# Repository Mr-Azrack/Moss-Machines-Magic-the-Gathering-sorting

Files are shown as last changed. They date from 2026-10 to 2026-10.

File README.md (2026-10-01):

# Moss Machine - Open Source Magic: The Gathering - MTG - Sorting & Recognition

<p align="center">
  
</p>

Welcome to the Moss Machine project! This open-source initiative provides a comprehensive system for automating the sorting, recognition, and management of Trading Card Game (TCG) cards. The system supports **317 different card games** including Magic: The Gathering, Pokemon, Yu-Gi-Oh!, and many others.

---

### Overview

The Moss Machine combines perceptual hash-based computer vision, multi-threaded processing, and hardware integration to create a high-performance, scalable card sorting solution. Whether you're a collector, player, or developer, this project offers tools and guidance to build your own automated card sorting system with speeds capable of processing cards in under 2 seconds per scan.

---

## Features

- **Open Source & Community Driven**  
  Fully open source code with transparent development. Contributions and modifications are encouraged—please credit the original source when creating derivatives.

- **Multi-Game Support**  
  - Supports **317 different trading card games** from a unified SQLite database
  - Includes Magic: The Gathering, Pokemon, Yu-Gi-Oh!, Flesh and Blood, Lorcana, and 300+ more
  - Filterable by game, set, rarity, and foil type for precise scanning
  - Automatic database download from server if not found locally

- **High-Performance Recognition Engine**  
  - **Perceptual hashing (pHash)** with 256-bit hash using 16x16 hash size for robust image matching
  - **RGB channel separation** - computes separate hashes for Red, Green, and Blue channels for improved accuracy
  - **Multi-threaded scanning** - parallel processing across games with 8 worker threads by default
  - **Early termination** - stops scanning immediately when exact match (distance = 0) is found
  - **Hash caching** - optional in-memory cache for popular games (Magic, Pokemon, Yu-Gi-Oh) for faster repeat scans
  - **Adaptive threshold scanning** - progressive tightening from strict to relaxed thresholds
  - **Quick distance pre-filtering** - rejects bad matches early using single-channel checks
  - **Hamming distance** calculation for fast hash comparison
  - **Average scan time** -: ~2 seconds per card across 317 games

- **Advanced Image Processing**  
  - **OpenCV-based** card detection with contour finding and perspective correction
  - **Automatic card orientation** - handles cards at any angle with 4-point perspective transform
  - **Region-based hashing** - uses top-left 745x745px crop for consistent hash generation
  - **VL6180X ToF sensor integration** - hardware distance sensing for precise Z-axis control during pickup/release
  - **Real-time camera feed processing** with automatic card detection

- **Flexible Sorting Modes**  
  - **Color sorting** - White, Blue, Black, Red, Green, Multicolor, Colorless, Land (Basic/Nonbasic)
  - **Mana value (CMC)** - Bins from 1-8+ with overflow handling
  - **Set code** - Sort by expansion/set with token detection
  - **Price-based** - 14 price brackets from $0.02 to $128+ with configurable thresholds
  - **Card type** - Creature, Artifact, Enchantment, Instant, Sorcery, Planeswalker, Battle, Land, Token
  - **Alphabetical (A-Z)** - First letter sorting with 0-9 bin for numbers/symbols
  - **Rarity** - Common, Uncommon, Rare, Mythic, Special, Bonus, Promo
  - **Finish** - Foil, Nonfoil, Both (for cards with multiple finishes)
  - **Buy mode** - Custom price threshold for purchase evaluation

- **Hardware Integration**  
  - **Arduino Mega control** via serial communication (PySerial)
  - **3-axis stepper motor control** (X, Y, Z axes plus dual E-motors for coordinated movement)
  - **Endstop sensors** on all 6 positions (X/Y/Z min/max) for safety and homing
  - **Dual vacuum system** - separate pickup and release control
  - **LED lighting control** for optimal camera visibility
  - **16x2 LCD display** (I2C) for real-time machine status
  - **34-tray sorting system** with configurable tray assignments
  - **Automatic homing and calibration** with configurable course correction
  - **Overflow tray (34)** and reject bin (33) with automatic routing
  - **Configurable parameters**: pickup/drop distances, movement speeds, thresholds, calibration multipliers
  - **Safety features**: endstop monitoring, retry logic (10 attempts), timeout handling
  - **Start/Stop machine states** - prevents accidental movements during parameter changes

- **GUI Control Interface**  
  - **Enhanced Tkinter GUI** with tabbed interface (Scanner, Arduino, Export)
  - **Live camera feed** display with real-time card detection overlay
  - **Manual and auto-scan modes** with configurable cooldown
  - **Arduino monitoring** - real-time sensor data display (range, endstops, motor states)
  - **Motor control panel** - manual control of X, Y, Z, E0, E1 motors
  - **Parameter upload/fetch** - live parameter editing and synchronization
  - **CSV export** - scan history with auto-export option
  - **Inventory tracking** - reject duplicate cards automatically
  - **Game/Set/Rarity/Foil filters** with dropdown selection
  - **Status logging** with color-coded messages

- **Performance & Reliability**  
  - **Detailed statistics** - tracks scans, total time, average time, cards checked, cache hits
  - **Retry mechanisms** - up to 10 pickup attempts with distance sensor verification
  - **Periodic homing** - automatic recalibration every N cards (configurable)
  - **Course correction** - fine-tune X/Y positioning to prevent drift
  - **Thread-local database connections** for safe multi-threading
  - **Confidence scoring** - percentage-based match quality with configurable minimum thresholds
  - **Duplicate detection** via inventory file tracking

- **Command Line Interface**  
  - Interactive mode with sorting menu
  - Realtime webcam mode for continuous scanning
  - Single-image scanning with detailed match output
  - Game/set/rarity/foil filtering via command-line arguments
  - List all games, sets, rarities, and foil types
  - Adjustable threshold and top-N results
  - Cache preloading option
  - Serial port and baud rate configuration

- **Configurable & Extensible**  
  - All movement parameters configurable (speeds, distances, calibration multipliers)
  - Adjustable hash matching thresholds (default: 10, lower = stricter)
  - Customizable tray assignments with automatic overflow
  - Price threshold configuration for buy mode
  - Worker thread count adjustable (default: 8)
  - Scan cooldown adjustable (default: 2.0 seconds)
  - Game-specific foil type and rarity detection

- **Technology Stack**  
  - **Python 3**: OpenCV (cv2), ImageHash, Pillow (PIL), PySerial, NumPy, SQLite3, Threading, Tkinter
  - **Database**: Unified SQLite database with 317 game-specific card tables, games table, sets table, and others (future development)
  - **Arduino**: C++ firmware for Mega 2560, Stepper motor control, I2C LCD, VL6180X ToF sensor (Adafruit library)
  - **Hardware**: RAMPS 1.4 board, A4988 stepper drivers, NEMA 17 motors, endstop switches, vacuum pumps, LED strips  

---

## System Architecture

### Software Components

1. **optimized_scanner.py** - Core recognition engine
   - `OptimizedCardScanner` class with multi-threaded game scanning
   - Perceptual hash computation and comparison
   - Database connection pooling (thread-local connections)
   - Adaptive threshold scanning
   - Serial communication with Arduino
   - Real-time webcam mode
   - Command-line interface with extensive filtering options

2. **gui_interface_enhanced.py** - GUI control interface
   - Tabbed interface (Scanner, Arduino, Export)
   - Live camera feed with card detection visualization
   - Arduino parameter management and monitoring
   - CSV export with scan history
   - Game/Set/Rarity/Foil filtering
   - Auto-scan and manual scan modes

3. **Main.ino** - Arduino firmware
   - 3-axis stepper motor control (X, Y, Z + E0, E1 dual drive)
   - VL6180X ToF sensor integration for distance measurement
   - Endstop monitoring (6 endstops: X/Y/Z min/max)
   - Dual vacuum system control
   - LCD status display (16x2 I2C)
   - Serial command parser with start/end markers
   - 34-tray coordinate system with automatic routing
   - Homing and calibration routines
   - State machine (Stopped/Started) for safe operation

### Database Structure

- **unified_card_database.db** (SQLite)
  - `games` table: 317 games with ID, name, display_name, total_cards
  - `cards_*` tables: One table per game (e.g., cards_magic, cards_pokemon, cards_yugioh)
  - `sets` table: Set information per game with set codes and card counts
  - Card columns: unique_id, product_id, set_code, rarity, name, series, number, prices (low/mid/high/market/imputed), subTypeName (foil type), has_image, phash (r_phash, g_phash, b_phash), extCardType
  - Optional: SKU columns (111 columns for condition/language/printing combinations)

### Hardware Components

- **Arduino Mega 2560** - Main controller
- **RAMPS 1.4** - Motor driver board
- **A4988 Stepper Drivers** (5x) - Motor control
- **NEMA 17 Stepper Motors** (5x) - X, Y, Z, E0, E1 axes
- **VL6180X ToF Sensor** - Distance measurement (I2C)
- **Endstop Switches** (6x) - Limit switches for safety
- **16x2 LCD Display** (I2C) - Status display
- **Vacuum Pumps** (2x) - Card pickup and release
- **LED Strip** - Lighting for camera
- **Webcam** - Card image capture

---

## Quick Start

### Software Setup

1. **Install Python dependencies:**
   ```bash
   pip install opencv-python pillow imagehash pyserial numpy
   ```

2. **Database:**
   - Place `unified_card_database.db` in the project directory
   - Or let the scanner auto-download from configured server URLs

3. **Run the scanner:**
   ```bash
   # Command-line mode (single image)
   python optimized_scanner.py card.jpg --cache

   # Interactive mode with Arduino
   python optimized_scanner.py --interactive --serial-port COM3

   # Realtime webcam mode
   python optimized_scanner.py --realtime --cache

   # GUI mode
   python gui_interface_enhanced.py
   ```

### Arduino Setup

1. **Install Arduino libraries:**
   - LiquidCrystal_I2C
   - Adafruit_VL6180X
   - Wire (built-in)
   - Stepper (built-in)

2. **Upload Main.ino** to Arduino Mega 2560

3. **Connect hardware:**
   - RAMPS 1.4 to Mega
   - Stepper motors to X, Y, Z, E0, E1 outputs
   - Endstops to min/max pins
   - VL6180X sensor to I2C (SDA/SCL)
   - LCD to I2C
   - Vacuum relays to pins 9 & 10
   - LED to pin 8

4. **Configure serial port** in Python scripts (default: COM3, 9600 baud)

### Usage Examples

```bash
# List all supported games
python optimized_scanner.py --list-games

# List sets for Magic (game ID 167)
python optimized_scanner.py --list-sets 167

# Scan a card, filter to Magic only
python optimized_scanner.py card.jpg -g Magic --cache

# Scan with set filter (Alpha and Beta)
python optimized_scanner.py card.jpg -s LEA -s LEB

# Filter by foil type and rarity
python optimized_scanner.py card.jpg -f Foil -r M -r R

# Adaptive scan with relaxed thresholds
python optimized_scanner.py card.jpg -t 20 --min-confidence 70
```

---

## Configuration

### Scanner Parameters (optimized_scanner.py)

- `max_workers`: Thread pool size (default: 8)
- `cache_enabled`: Enable in-memory hash caching (default: True)
- `threshold`: Match threshold, lower = stricter (default: 10)
- `top_n`: Number of top matches to return (default: 10)
- `min_confidence`: Minimum confidence % for Method 1 (default: 85.0)
- `scan_cooldown`: Seconds between auto-scans (default: 2.0)

### Arduino Parameters (Main.ino)

- `Xcal`, `Ycal`, `Zcal`: Movement calibration multipliers (350, 475, 140)
- `speed`: XY movement speed in microseconds (default: 700)
- `zspeed`, `zespeed`: Z-axis speeds (75, 120)
- `initial_pickup_distance`: Z distance to pickup position (6000 steps)
- `initial_drop_distance`: Z distance to drop position (4000 steps)
- `pickup_threshold`: Distance threshold for successful pickup (40mm)
- `release_threshold`: Distance threshold for successful release (40mm)
- `HCC`: Homing cycle count - rehome every N cards (default: 10)
- `XCourseCorrection`, `YCourseCorrection`: Fine-tune positioning (0, 1)

### Tray Layout (Main.ino)

- **Trays 1-32**: Configurable card bins
- **Tray 33**: RejectCard bin (reserved)
- **Tray 34**: OverflowTray (reserved)
- Coordinate arrays: `X[6][5]` and `Y[4][7]` define physical tray positions

---

## Pictures


---

### Disclaimer

- The project is open source and may evolve significantly over time.  
- All code is thoroughly tested but may require calibration based on your hardware setup.  
- Use caution—never put valuable cards in the machine without testing.  
- If you modify or create your own variations, please credit the original source.

---

## Build Your Own

### Get Started
- All necessary files, including code, 3D print files, and hardware schematics, are available in this repository.
- Follow the detailed instructions within the Discord under #assembly

---

## Legal & Usage Notice

**Disclaimer:**  
This system is intended for hobbyist and educational use. Always test with non-valuable cards first. Handle valuable or rare cards with care—never trust automated sorting in critical scenarios. The project is open source; use at your own risk.

---

## Connect with Us & Follow

| Discord Logo | Reddit Logo | GitHub Logo |
|:---:|:---:|:---:|
| **Join our Discord:**<br>[https://discord.gg/2gNWpV6UjW](https://discord.gg/2gNWpV6UjW) | **Reddit:**<br>[r/MossMachine](https://www.reddit.com/r/MossMachine/) | **Repository:**<br>[GitHub](https://github.com/KairiCollections/Moss-Machine---Magic-the-Gathering-recognition-and-sorting-machine) |

---

## Support
Help keep my motivation
- Patreon - https://www.patreon.com/KairiCollections
- By me a coffee - https://www.buymeacoffee.com/KairiCollections
- Ko-fi - http://ko-fi.com/kairiskyewillow

Other non-related support:
- https://www.etsy.com/shop/KairiCollections

---

## Acknowledgments & License

This project is licensed under the **Creative Commons Attribution-NonCommercial-ShareAlike 4.0 International License (CC BY-NC-SA 4.0)**.  
Please give credit to the original authors when creating derivatives.

---

**Happy Sorting!**

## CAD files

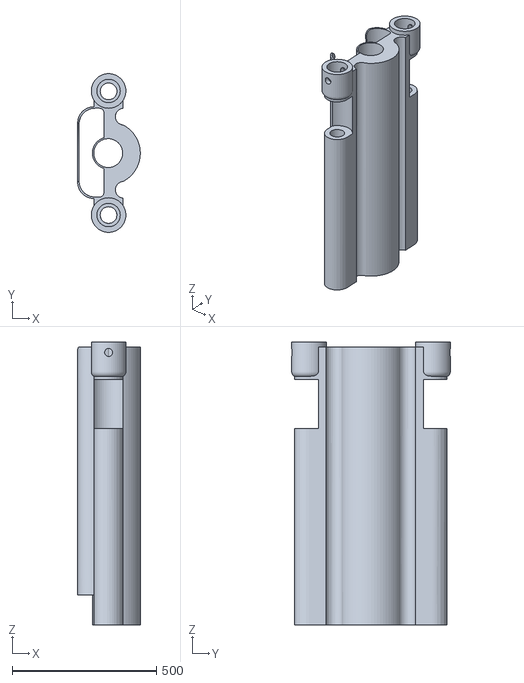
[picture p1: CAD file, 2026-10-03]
3D print/Axis/Axis - Z/new extension.stl
217.1 x 550.0 x 980.5

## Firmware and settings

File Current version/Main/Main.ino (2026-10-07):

#include <LiquidCrystal_I2C.h>
#include <Stepper.h>
#include <Wire.h>
#include "Adafruit_VL6180X.h"

// ============================================================
// ERROR CODES — mirrors error_codes.py on the PC side
// Format: <Error,EXXX,short description>
// ============================================================
#define EC_TOF_NOT_FOUND      "E501"
#define EC_TOF_SYS_ERR        "E502"
#define EC_TOF_ECE            "E503"
#define EC_TOF_NO_CONVERGE    "E504"
#define EC_PICKUP_RETRY       "E505"
#define EC_OVERFLOW_FULL      "E506"
#define EC_CMD_NOT_STARTED    "E507"
#define EC_CMD_STARTED        "E508"
#define EC_NOT_AT_HOME        "E509"
#define EC_HOME_X_FAIL        "E510"
#define EC_HOME_Y_FAIL        "E511"
#define EC_HOME_Z_FAIL        "E512"
#define EC_BUF_OVERFLOW       "E513"
#define EC_UNKNOWN_CMD        "E514"

#define REPORT_ERROR(code, msg) \
  do { \
    Serial.println("<Error," + String(code) + "," + String(msg) + ">"); \
    lcd.setCursor(0, 1); lcd.print(String(code) + " " + String(msg).substring(0, 11)); \
  } while(0)

enum Pins {
    Zmin = 18, Xmin = 3, Ymin = 14, Xmax = 2, Ymax = 15, Zmax = 19,
    Lights = 8, Vacuum1 = 9, Vacuum2 = 10,
    Xenable = 38, Yenable = 56, Zenable = 62, E0enable = 24, E1enable = 30,
    Xstep = 54, Ystep = 60, Zstep = 46, E0step = 26, E1step = 36,
    Xdir = 55, Ydir = 61, Zdir = 48, E0dir = 28, E1dir = 34
};

Adafruit_VL6180X vl = Adafruit_VL6180X();
LiquidCrystal_I2C lcd(0x27, 16, 2);

boolean newData = false, readInProgress = false, newDataFromPC = false;
boolean atHomePosition = true;
boolean machineStarted = false;
boolean abortRequested = false;
byte bytesRecvd = 0, PickupRetry;
const byte numChars = 64, buffSize = 40;
const char startMarker = '<', endMarker = '>';
char inputBuffer[buffSize], messageFromPC[buffSize] = { 0 }, receivedChars[numChars];

float timeoutcount = 0;
const float timeout = 10;

const char* MatchingValues[] = {"RejectCard", "tray1", "tray7", "tray14", "tray18","tray25", "tray26", "tray27", "tray28", "tray29", "tray30", "tray31", "tray32"};
const int loopStart[] = {33, 1, 7, 14, 18, 25, 26, 27, 28, 29, 30, 31, 32};
const int loopEnd[] = {33, 6, 13, 17, 24, 25, 26, 27, 28, 29, 30, 31, 32};
boolean match = 0;
const int xOffsets[6] = {-3, -2, -1, 1, 2, 3};
const int yOffsets[4] = {-2, -1, 1, 2};
const short X[6][5]={{31,27,21,28,32},{23,11,9,12,24},{17,5,1,6,18},{19,7,2,8,20},{25,13,10,14,26},{33,29,22,30,34}};
const short Y[4][7]={{32,24,18,16,20,26,34},{28,12,6,4,8,14,30},{27,11,5,3,7,13,29},{31,23,17,15,19,25,33}};
short CountArray[35], upcount;
String AssignedTrayValue[35], Tempval1;
uint8_t range[6];

byte X_ENDSTOP_MIN, Y_ENDSTOP_MIN, Z_ENDSTOP_MIN, X_ENDSTOP_MAX, Y_ENDSTOP_MAX, Z_ENDSTOP_MAX;
long zPositionSteps = 0;
const long Z_SOFT_MAX_STEPS = 93500L;
const short PICKUP_CONTACT_MM = 5;
const long PICKUP_COMPRESSION_STEPS = 1000L;  // ~1.1 mm extra cup compression at Zcal 935.
const byte MAX_PICKUP_ATTEMPTS = 3;
const unsigned short PICKUP_VACUUM_PULSE_MS = 750;
const unsigned short RELEASE_PULSE_MS = 250;

short initial_pickup_distance = 6000, initial_drop_distance = 4000;
short Xcal = 350, Ycal = 475, Zcal = 935;
short speed = 700, zspeed = 40, zespeed = 55;
short pickup_threshold = 40, release_threshold = 40;
short HCC = 10, YCourseCorrection = 1, XCourseCorrection = 0;

void setup() {
  byte pins[] = { Xstep, Ystep, Zstep, E0step, E1step, Xdir, Ydir, Zdir, E0dir, E1dir, Xenable, Yenable, Zenable, E0enable, E1enable, Vacuum1, Vacuum2, Lights};
  for (byte pin : pins) { pinMode(pin, OUTPUT); }

  digitalWrite(Xenable, LOW);
  digitalWrite(Yenable, LOW);
  digitalWrite(Zenable, LOW);
  digitalWrite(E0enable, LOW);
  digitalWrite(E1enable, LOW);
  digitalWrite(Vacuum1, LOW);
  digitalWrite(Vacuum2, LOW);
  digitalWrite(Lights, HIGH);

  Serial.begin(9600);
  Serial.setTimeout(100);
  digitalWrite(13, HIGH);
  while (!Serial) { delay(10); }
  Serial.println("Adafruit VL6180x test!");
  while (!vl.begin()) {
    REPORT_ERROR(EC_TOF_NOT_FOUND, "No ToF sensor");
    PrintLCD("E501 No ToF", "Check I2C wiring");
    delay(1000);
  }
  Serial.println("Sensor found!");
  PrintLCD("ToF sensor", "found");
  Homemachine();
  delay(100);
  Serial.println("<Arduino is ready>");
}

void loop() {
  uint8_t status = vl.readRangeStatus();
  if (AssignedTrayValue[34] != "OverflowTray") {AssignedTrayValue[34] = "OverflowTray";}
  if (AssignedTrayValue[33] != "RejectCard") {AssignedTrayValue[33] = "RejectCard";}

  if (status == VL6180X_ERROR_NONE) {
    ReadRange(1);
    Serial.print("Range: ");
    Serial.println((range[0] + range[1]) / 2);
  } else {
    PrintLCD("ToF: No range", " ");
  }

  switch (status) {
    case VL6180X_ERROR_SYSERR_1 ... VL6180X_ERROR_SYSERR_5:
      REPORT_ERROR(EC_TOF_SYS_ERR, "System error"); break;
    case VL6180X_ERROR_ECEFAIL:
      REPORT_ERROR(EC_TOF_ECE, "ECE failure"); break;
    case VL6180X_ERROR_NOCONVERGE:
      REPORT_ERROR(EC_TOF_NO_CONVERGE, "No convergence"); break;
    case VL6180X_ERROR_RANGEIGNORE:
      Serial.println("<Info,E504,Ignoring range>"); break;
    case VL6180X_ERROR_SNR:
      REPORT_ERROR(EC_TOF_SYS_ERR, "Signal/Noise err"); break;
    case VL6180X_ERROR_RAWUFLOW:
      REPORT_ERROR(EC_TOF_SYS_ERR, "Raw underflow"); break;
    case VL6180X_ERROR_RAWOFLOW:
      REPORT_ERROR(EC_TOF_SYS_ERR, "Raw overflow"); break;
    case VL6180X_ERROR_RANGEUFLOW:
      REPORT_ERROR(EC_TOF_SYS_ERR, "Range underflow"); break;
    case VL6180X_ERROR_RANGEOFLOW:
      REPORT_ERROR(EC_TOF_SYS_ERR, "Range overflow"); break;
    default: break;
  }

  lcd.init();
  lcd.backlight();
  lcd.setCursor(0, 0);
  ReadEndstops();
  PrintLCD("Ready", " ");

  Tempval1 = Serial.readString();
  delay(10);
  Tempval1.trim();
  if (Tempval1 != "") {
    PrintLCD("Received: ", Tempval1);
    ReadRange(1);
    DetermineAction();
    Serial.println("<Arduino is ready>");
    timeoutcount = 0;
  }

  Tempval1 = "";
  messageFromPC == "";
  bytesRecvd == 0;
  newData = false;
  readInProgress = false;
  newDataFromPC = false;
}

void getDataFromPC() {
  if (Serial.available() > 0) {
    char x = Serial.read();
    if (x == endMarker) {
      readInProgress = false;
      newDataFromPC = true;
      inputBuffer[bytesRecvd] = 0;
      parseData();
    }
    if (readInProgress) {
      inputBuffer[bytesRecvd] = x;
      bytesRecvd++;
      if (bytesRecvd == buffSize) {
        bytesRecvd = buffSize - 1;
        REPORT_ERROR(EC_BUF_OVERFLOW, "Cmd truncated");
      }
    }
    if (x == startMarker) {
      bytesRecvd = 0;
      readInProgress = true;
    }
  }
}

void parseData() {
  char* strtokIndx;
  strtokIndx = strtok(inputBuffer, ",");
  strcpy(messageFromPC, strtokIndx);
  strtokIndx = strtok(NULL, ",");
  strtokIndx = strtok(NULL, ",");
}

boolean checkEmergencyStop() {
  if (abortRequested) return true;
  if (!machineStarted || Serial.available() <= 0) return false;

  String incoming = Serial.readString();
  incoming.trim();
  if (incoming == "StopMachine") {
    abortRequested = true;
    machineStarted = false;
    digitalWrite(Vacuum1, LOW);
    digitalWrite(Vacuum2, LOW);
    Serial.println("<OK,MachineStopped>");
    PrintLCD("STOPPED", "Cycle aborted");
    return true;
  }

  return false;
}

boolean delayWithStop(unsigned long waitMs) {
  unsigned long startedAt = millis();
  while (millis() - startedAt < waitMs) {
    if (abortRequested) return false;
    if (machineStarted && checkEmergencyStop()) return false;
    delay(10);
  }
  return true;
}

boolean pick(long steps, byte Release) {
  if (Release == 1) {
    Move1(0, steps, zspeed);
    if (abortRequested) return false;

    digitalWrite(Vacuum1, LOW);
    if (!delayWithStop(100)) return false;

    MotorsOnOff(1);
    if (!delayWithStop(100)) return false;

    digitalWrite(Vacuum2, HIGH);
    if (!delayWithStop(RELEASE_PULSE_MS)) {
      digitalWrite(Vacuum2, LOW);
      return false;
    }
    digitalWrite(Vacuum2, LOW);

    MotorsOnOff(0);
    if (!delayWithStop(100)) return false;
    Move1(1, steps, zespeed);
    return !abortRequested;
  }

  PickupRetry = 0;
  while (PickupRetry < MAX_PICKUP_ATTEMPTS) {
    Move1(0, steps, zspeed);
    if (abortRequested) return false;

    // Active pickup mode: pulse Vac1 long enough to establish the seal,
    // then shut the pump off before lifting.  The vacuum line/cup should
    // retain enough vacuum to carry the card mechanically.
    digitalWrite(Vacuum1, HIGH);
    if (!delayWithStop(PICKUP_VACUUM_PULSE_MS)) {
      digitalWrite(Vacuum1, LOW);
      return false;
    }
    digitalWrite(Vacuum1, LOW);

    // Previous continuous-hold pickup mode retained here for easy rollback.
    // To restore it, replace the pulse block above and the Move1 block below
    // with this commented section.
    /*
    digitalWrite(Vacuum1, HIGH);
    if (!delayWithStop(1000)) {
      digitalWrite(Vacuum1, LOW);
      return false;
    }

    Move1(1, steps, zespeed);
    if (abortRequested) {
      digitalWrite(Vacuum1, LOW);
      return false;
    }
    */

    Move1(1, steps, zespeed);
    if (abortRequested) return false;

    ReadRange(3);
    if (((range[2] + range[3]) / 2) <= pickup_threshold) {
      return true;
    }

    PickupRetry++;
    if (PickupRetry < MAX_PICKUP_ATTEMPTS) {
      if (!delayWithStop(150)) return false;
    }
  }

  digitalWrite(Vacuum1, LOW);
  digitalWrite(Vacuum2, LOW);
  machineStarted = false;
  REPORT_ERROR(EC_PICKUP_RETRY, "3 retries failed");
  PrintLCD("E505 Pickup", "Cycle stopped");
  return false;
}

void Homemachine() {
  PrintLCD("Calibrating", " ");
  atHomePosition = false;
  ReadEndstops();

  if (Z_ENDSTOP_MIN == 1) {
    unsigned long t0 = millis();
    while (Z_ENDSTOP_MIN == 1) {
      Move1(1, 3, zespeed);
      Z_ENDSTOP_MIN = digitalRead(Zmin);
      if (millis() - t0 > 60000UL) {
        REPORT_ERROR(EC_HOME_Z_FAIL, "Z endstop");
        PrintLCD("E512 Z home", "Motion aborted");
        return;
      }
    }
    delay(200);
  }

  if (Y_ENDSTOP_MIN == 1) {
    Move4(1, 0, 0, 50);
    unsigned long t1 = millis();
    while (Y_ENDSTOP_MIN == 1) {
      Move4(0, 1, 0, 5);
      Y_ENDSTOP_MIN = digitalRead(Ymin);
      if (millis() - t1 > 10000) {
        REPORT_ERROR(EC_HOME_Y_FAIL, "Y endstop");
        break;
      }
    }
    delay(200);
  }

  if (X_ENDSTOP_MAX == 1) {
    Move4(1, 0, 50, 0);
    unsigned long t2 = millis();
    while (X_ENDSTOP_MAX == 1) {
      Move4(0, 1, 3, 0);
      X_ENDSTOP_MAX = digitalRead(Xmax);
      if (millis() - t2 > 10000) {
        REPORT_ERROR(EC_HOME_X_FAIL, "X endstop");
        break;
      }
    }
    delay(200);
  }

  Move1(0, 3000, zspeed);
  delay(200);
  Move4(1, 0, Xcal * 3 + 55, Ycal * 2 + 38);
  delay(200);
  zPositionSteps = 0;
  abortRequested = false;
  atHomePosition = true;
}

void StopMachine() {
  abortRequested = true;
  machineStarted = false;
  digitalWrite(Vacuum1, LOW);
  digitalWrite(Vacuum2, LOW);
  PrintLCD("STOPPED", "Cycle aborted");
}

void ReadEndstops() {
  X_ENDSTOP_MIN = digitalRead(Xmin);
  X_ENDSTOP_MAX = digitalRead(Xmax);
  Y_ENDSTOP_MIN = digitalRead(Ymin);
  Y_ENDSTOP_MAX = digitalRead(Ymax);
  Z_ENDSTOP_MIN = digitalRead(Zmin);
  Z_ENDSTOP_MAX = digitalRead(Zmax);
}

void MotorsOnOff(boolean OnOff) {
  digitalWrite(Xenable, OnOff);
  digitalWrite(E0enable, OnOff);
  digitalWrite(Yenable, OnOff);
  digitalWrite(E1enable, OnOff);
  digitalWrite(Zenable, OnOff);
}

void DetermineAction() {
  boolean sortCommand = false;
  if (Tempval1.startsWith("Sort,")) {
    Tempval1 = Tempval1.substring(5);
    Tempval1.trim();
    sortCommand = true;

    if (Tempval1.length() == 0) {
      REPORT_ERROR(EC_UNKNOWN_CMD, "Empty sort");
      return;
    }
  }

  if (sortCommand) {
    if (!machineStarted) {
      REPORT_ERROR(EC_CMD_NOT_STARTED, "Start machine");
      PrintLCD("E507 Stopped", "Start machine!");
      return;
    }

    abortRequested = false;

    for (int i = 0; i < sizeof(MatchingValues) / sizeof(MatchingValues[0]); ++i) {
      if (Tempval1 == MatchingValues[i]) {
        atHomePosition = false;
        ForLoop(loopStart[i], loopEnd[i]);
        if (!abortRequested) atHomePosition = true;
        return;
      }
    }

    atHomePosition = false;
    ForLoop(1, 34);
    if (!abortRequested) atHomePosition = true;
    return;
  }

  long manualSteps = 5;
  int commaIdx = Tempval1.indexOf(',');
  if (commaIdx > 0) {
    String commandName = Tempval1.substring(0, commaIdx);
    if (commandName == "CalibrateX1" || commandName == "CalibrateX2" ||
        commandName == "CalibrateY1" || commandName == "CalibrateY2" ||
        commandName == "CalibrateZ1" || commandName == "CalibrateZ2") {
      String stepStr = Tempval1.substring(commaIdx + 1);
      stepStr.trim();
      long parsed = stepStr.toInt();
      if (parsed > 0) manualSteps = parsed;
      Tempval1 = commandName;
    }
  }

  if (Tempval1 == "StartMachine") {
    abortRequested = false;
    machineStarted = true;
    Serial.println("<OK,MachineStarted>");
    PrintLCD("Machine STARTED", "Accepting cards");
    return;
  } else if (Tempval1 == "StopMachine") {
    StopMachine();
    Serial.println("<OK,MachineStopped>");
    return;
  }

  for (int i = 0; i < sizeof(MatchingValues) / sizeof(MatchingValues[0]); ++i) {
    if (Tempval1 == MatchingValues[i]) {
      if (!machineStarted) {
        REPORT_ERROR(EC_CMD_NOT_STARTED, "Start machine");
        PrintLCD("E507 Stopped", "Start machine!");
        return;
      }
      match = 1;
      atHomePosition = false;
      ForLoop(loopStart[i], loopEnd[i]);
      if (!abortRequested) atHomePosition = true;
      break;
    }
  }

  if (Tempval1 == "CalibrateX1" || Tempval1 == "CalibrateX2" ||
      Tempval1 == "CalibrateY1" || Tempval1 == "CalibrateY2" ||
      Tempval1 == "CalibrateZ1" || Tempval1 == "CalibrateZ2" ||
      Tempval1 == "HomeButton") {
    if (machineStarted) {
      REPORT_ERROR(EC_CMD_STARTED, "Stop machine");
      PrintLCD("E508 Started", "Stop machine!");
      return;
    }
  }

  if (Tempval1 == "CalibrateX1") {Move4(0,1,(short)manualSteps,0);
  } else if (Tempval1 == "CalibrateX2") {Move4(1,1,(short)manualSteps,0);
  } else if (Tempval1 == "CalibrateY1") {Move4(0,0,0,(short)manualSteps);
  } else if (Tempval1 == "CalibrateY2") {Move4(0,1,0,(short)manualSteps);
  } else if (Tempval1 == "CalibrateZ1") {Move1(0,manualSteps,zspeed);
  } else if (Tempval1 == "CalibrateZ2") {Move1(1,manualSteps,zespeed);
  } else if (Tempval1 == "HomeButton") {Homemachine();

  } else if (Tempval1 == "QuerySensors") {
    ReadRange(1);
    ReadEndstops();
    String response = "<Sensors,range=";
    response += String((range[0] + range[1]) / 2);
    response += ",xmin=" + String(X_ENDSTOP_MIN);
    response += ",xmax=" + String(X_ENDSTOP_MAX);
    response += ",ymin=" + String(Y_ENDSTOP_MIN);
    response += ",ymax=" + String(Y_ENDSTOP_MAX);
    response += ",zmin=" + String(Z_ENDSTOP_MIN);
    response += ",zmax=" + String(Z_ENDSTOP_MAX);
    response += ",zsteps=" + String(zPositionSteps);
    response += ",home=" + String(atHomePosition ? 1 : 0);
    response += ",started=" + String(machineStarted ? 1 : 0);
    response += ">";
    Serial.println(response);

  } else if (Tempval1.startsWith("SetMotor,")) {
    if (machineStarted) {
      REPORT_ERROR(EC_CMD_STARTED, "Stop first");
      return;
    }

    int comma1 = Tempval1.indexOf(',');
    int comma2 = Tempval1.indexOf(',', comma1 + 1);
    String motor = Tempval1.substring(comma1 + 1, comma2);
    int state = Tempval1.substring(comma2 + 1).toInt();

    if (motor == "Xenable") digitalWrite(Xenable, state);
    else if (motor == "Yenable") digitalWrite(Yenable, state);
    else if (motor == "Zenable") digitalWrite(Zenable, state);
    else if (motor == "E0enable") digitalWrite(E0enable, state);
    else if (motor == "E1enable") digitalWrite(E1enable, state);
    else if (motor == "Vacuum1") digitalWrite(Vacuum1, state);
    else if (motor == "Vacuum2") digitalWrite(Vacuum2, state);
    else if (motor == "Lights") digitalWrite(Lights, state);

    Serial.println("<OK,Motor=" + motor + ",State=" + String(state) + ">");

  } else if (Tempval1.startsWith("SetParam,")) {
    if (machineStarted) {
      REPORT_ERROR(EC_CMD_STARTED, "Stop first");
      return;
    }
    if (!atHomePosition) {
      REPORT_ERROR(EC_NOT_AT_HOME, "Home first");
      return;
    }

    int comma1 = Tempval1.indexOf(',');
    int comma2 = Tempval1.indexOf(',', comma1 + 1);
    String param = Tempval1.substring(comma1 + 1, comma2);
    int value = Tempval1.substring(comma2 + 1).toInt();

    if (param == "speed") speed = value;
    else if (param == "zspeed") zspeed = value;
    else if (param == "zespeed") zespeed = value;
    else if (param == "xcal") Xcal = value;
    else if (param == "ycal") Ycal = value;
    else if (param == "zcal") Zcal = value;
    else if (param == "pickup_thresh") pickup_threshold = value;
    else if (param == "release_thresh") release_threshold = value;
    else if (param == "hcc") HCC = value;
    else if (param == "ycc") YCourseCorrection = value;
    else if (param == "xcc") XCourseCorrection = value;

    Serial.println("<OK,Param=" + param + ",Value=" + String(value) + ">");

  } else if (Tempval1 == "QueryParams") {
    String response = "<Params";
    response += ",speed=" + String(speed);
    response += ",zspeed=" + String(zspeed);
    response += ",zespeed=" + String(zespeed);
    response += ",xcal=" + String(Xcal);
    response += ",ycal=" + String(Ycal);
    response += ",zcal=" + String(Zcal);
    response += ",pickup_thresh=" + String(pickup_threshold);
    response += ",release_thresh=" + String(release_threshold);
    response += ",hcc=" + String(HCC);
    response += ",ycc=" + String(YCourseCorrection);
    response += ",xcc=" + String(XCourseCorrection);
    response += ">";
    Serial.println(response);

  } else if (match == 1) {
    match = 0;
  } else {
    REPORT_ERROR(EC_UNKNOWN_CMD, Tempval1.substring(0,10));
  }
}

void ForLoop(byte first, byte last) {
  for (byte i = first; i <= last; i++) {
    if (abortRequested || !machineStarted) break;

    if (AssignedTrayValue[i] == "") {
      AssignedTrayValue[i] = Tempval1;
      PrintLCD("Tray assigned ", Tempval1);
      delay(10);
    }

    if (AssignedTrayValue[i] == Tempval1 && CountArray[i] <= 375) {
      Tray(i);
      if (!abortRequested && machineStarted) {
        Serial.println((String) "Went to tray" + i);
      }
      break;
    } else if (i == 34 && CountArray[34] < 375) {
      Tray(34);
      break;
    } else if (i == 34 && CountArray[34] >= 375) {
      REPORT_ERROR(EC_OVERFLOW_FULL, "Tray 34 full");
      StopMachine();
      Tempval1 = "";
      break;
    }
  }
}

void Tray(short var) {
  atHomePosition = false;
  Move1(0, initial_pickup_distance, zspeed);
  if (abortRequested) return;
  ReadRange(1);

  long pickupRangeMm = ((long)range[0] + (long)range[1]) / 2L;
  long remainingMm = pickupRangeMm - (long)PICKUP_CONTACT_MM;
  if (remainingMm < 0) remainingMm = 0;
  long pickupSteps = remainingMm * (long)Zcal;
  pickupSteps += PICKUP_COMPRESSION_STEPS;

  long remainingSafeSteps = Z_SOFT_MAX_STEPS - zPositionSteps;
  if (remainingSafeSteps < 0) remainingSafeSteps = 0;
  if (pickupSteps > remainingSafeSteps) pickupSteps = remainingSafeSteps;

  if (!pick(pickupSteps, 0)) {
    // A normal pickup failure leaves Z at the initial 6000-step pickup height.
    // Return to home height.  An emergency stop, however, stops immediately.
    if (!abortRequested) {
      Move1(1, initial_pickup_distance, zespeed);
      zPositionSteps = 0;
      atHomePosition = true;
    }
    return;
  }

  upcount++;
  CountArray[var]++;

  short x = 0, y = 0;
  boolean xFound = false, yFound = false;

  for (byte row = 0; row < 6 && !xFound; row++) {
    for (byte col = 0; col < 5; col++) {
      if (X[row][col] == var) {
        x = xOffsets[row];
        xFound = true;
        break;
      }
    }
  }

  for (byte row = 0; row < 4 && !yFound; row++) {
    for (byte col = 0; col < 7; col++) {
      if (Y[row][col] == var) {
        y = yOffsets[row];
        yFound = true;
        break;
      }
    }
  }

  int absX = abs(Xcal * x);
  int absY = abs(Ycal * y);
  int moveToDirectionX = (x >= 0) ? 1 : 0;
  int moveToDirectionY = (y >= 0) ? 0 : 1;
  Move4(moveToDirectionX, moveToDirectionY, absX, absY);
  if (abortRequested) return;

  if (!pick(initial_drop_distance, 1)) return;
  if (abortRequested) return;

  int moveBackDirectionX = (x >= 0) ? 0 : 1;
  int moveBackDirectionY = (y >= 0) ? 1 : 0;
  Move4(moveBackDirectionX, moveBackDirectionY, absX, absY);
  if (abortRequested) return;

  Move1(1, initial_pickup_distance, zespeed);
  if (abortRequested) return;

  if (y != 0) { Move4(0, 0, 0, YCourseCorrection); }
  if (x != 0) { Move4(0, 1, XCourseCorrection, 0); }
  if (abortRequested) return;

  if (upcount % HCC == 0 && upcount >= HCC / 2) {
    Homemachine();
  }
  atHomePosition = true;
}

void Move4(boolean dir1, boolean dir3, short steps1, short steps2) {
  boolean dir2;
  if (dir1 == 0) {dir2 = 1;} else {dir2 = 0;}
  digitalWrite(Xdir, dir1);
  digitalWrite(E0dir, dir2);
  digitalWrite(Ydir, dir3);
  digitalWrite(E1dir, dir3);

  for (short i = 0; (i < steps1 || i < steps2); i++) {
    if (abortRequested) break;
    if (machineStarted && (i % 25 == 0) && checkEmergencyStop()) break;

    if (i < steps1) {
      digitalWrite(Xstep, HIGH);
      digitalWrite(E0step, HIGH);
    }
    if (i < steps2) {
      digitalWrite(Ystep, HIGH);
      digitalWrite(E1step, HIGH);
    }
    delayMicroseconds(speed);
    digitalWrite(Xstep, LOW);
    digitalWrite(E0step, LOW);
    digitalWrite(Ystep, LOW);
    digitalWrite(E1step, LOW);
    delayMicroseconds(speed);
  }
}
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

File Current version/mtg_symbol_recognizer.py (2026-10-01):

#!/usr/bin/env python3
"""
Magic the Gathering Symbol Recognition Tool

This tool helps identify set symbols on MTG cards by:
1. Loading card images from the database (product_id.jpg)
2. Allowing users to click two points to define a region of interest
3. Matching the region against set symbol templates
4. Determining the set code based on the symbol match

Usage:
  python mtg_symbol_recognizer.py                    # Interactive mode (single card)
  python mtg_symbol_recognizer.py --batch <SET>     # Batch test mode for a set
  python mtg_symbol_recognizer.py <image_path>     # Test specific image
"""

import cv2
import numpy as np
import sqlite3
from pathlib import Path
import os
import sys
import argparse
import json
try:
    import torch
    import torch.nn as nn
    from torchvision import models
    _TORCH_AVAILABLE = True
except BaseException:
    _TORCH_AVAILABLE = False

# Configuration
PROJECT_ROOT = Path(__file__).resolve().parent
DB_PATH = PROJECT_ROOT / "unified_card_database.db"  # Root DB, not instance
VECTORS_PATH = PROJECT_ROOT / "Magic the Gathering Vectors" / "Set symbols" / "Physical"
TEMPLATES_BASE_PATH = PROJECT_ROOT / "mtg_symbol_templates"
TEMPLATES_PATH = TEMPLATES_BASE_PATH / "max150"
IMAGE_BASE_PATH = PROJECT_ROOT / "static"
MAGIC_TABLE = "cards_1"  # Magic the Gathering is game_id 1
ROI_CONFIG_PATH = PROJECT_ROOT / "mtg_set_roi_locations.json"
MODEL_PATH = PROJECT_ROOT / "models" / "rarity_cnn.pt"
SET_MODEL_PATH = PROJECT_ROOT / "models" / "set_cnn.pt"

# Global variables for ROI selection
points = []
roi_coords = None  # Stored ROI coordinates for batch mode
image_display = None
window_name = "MTG Symbol Recognition - Click 2 points to define ROI"

# ML model cache
_RARITY_MODEL = None
_RARITY_CLASS_MAP = None
_RARITY_IMAGE_SIZE = 64
_SET_MODEL = None
_SET_CLASS_MAP = None
_SET_IMAGE_SIZE = 64
_SET_SYMBOLS = None
_TEMPLATE_FEATURE_CACHE = {}



def get_random_magic_card():
    """Get a random Magic the Gathering card from the database"""
    conn = sqlite3.connect(str(DB_PATH))
    cur = conn.cursor()
    
    # Get a random card with an image and set_code
    cur.execute(f"""
        SELECT product_id, name, set_code, rarity 
        FROM {MAGIC_TABLE} 
        WHERE has_image = 1 
        AND set_code IS NOT NULL
        AND set_code != ''
        ORDER BY RANDOM() 
        LIMIT 1
    """)
    
    result = cur.fetchone()
    conn.close()
    
    if result:
        return {
            'product_id': result[0],
            'name': result[1],
            'set_code': result[2],
            'rarity': result[3]
        }
    return None


def get_cards_by_set_and_rarity(set_code, rarity=None, limit=10):
    """Get cards from a specific set, optionally filtered by rarity"""
    conn = sqlite3.connect(str(DB_PATH))
    cur = conn.cursor()
    
    if rarity:
        cur.execute(f"""
            SELECT product_id, name, set_code, rarity 
            FROM {MAGIC_TABLE} 
            WHERE set_code = ? 
            AND rarity = ?
            AND has_image = 1 
            ORDER BY RANDOM() 
            LIMIT ?
        """, (set_code, rarity, limit))
    else:
        cur.execute(f"""
            SELECT product_id, name, set_code, rarity 
            FROM {MAGIC_TABLE} 
            WHERE set_code = ? 
            AND has_image = 1 
            ORDER BY rarity, RANDOM()
            LIMIT ?
        """, (set_code, limit))
    
    results = cur.fetchall()
    conn.close()
    
    cards = []
    for result in results:
        cards.append({
            'product_id': result[0],
            'name': result[1],
            'set_code': result[2],
            'rarity': result[3]
        })
    return cards


def find_card_image(product_id):
    """Find the card image file by product_id"""
    # Search in common locations for Magic (game_id 1)
    search_paths = [
        IMAGE_BASE_PATH / "Originals" / f"{product_id}.jpg",
        PROJECT_ROOT / "Data" / "1" / f"{product_id}.jpg",
        PROJECT_ROOT / "Collection" / f"{product_id}.jpg",
    ]
    
    for path in search_paths:
        if path.exists():
            return path
    
    # Search recursively in static folder as fallback
    for path in IMAGE_BASE_PATH.rglob(f"{product_id}.jpg"):
        return path
    
    return None


def load_set_symbols(force_reload=False):
    """Load all available set symbol templates (cached per process)."""
    global _SET_SYMBOLS
    if _SET_SYMBOLS is not None and not force_reload:
        return _SET_SYMBOLS

    symbols = {}

    # Prefer pre-rendered PNG templates if available
    if TEMPLATES_PATH.exists():
        print(f"Loading templates from: {TEMPLATES_PATH}")
        for set_folder in TEMPLATES_PATH.iterdir():
            if set_folder.is_dir():
                set_code = set_folder.name
                symbols[set_code] = {}

                for symbol_file in set_folder.glob("*.png"):
                    rarity = symbol_file.stem  # C, R, M, etc.
                    symbols[set_code][rarity] = symbol_file

        print(f"Loaded {len(symbols)} set symbol templates (PNG)")
        _SET_SYMBOLS = symbols
        return _SET_SYMBOLS

    # Fallback to SVG vectors
    if not VECTORS_PATH.exists():
        print(f"Vectors path not found: {VECTORS_PATH}")
        _SET_SYMBOLS = symbols
        return _SET_SYMBOLS

    print(f"Loading templates from: {VECTORS_PATH}")
    for set_folder in VECTORS_PATH.iterdir():
        if set_folder.is_dir():
            set_code = set_folder.name
            symbols[set_code] = {}

            for symbol_file in set_folder.glob("*.svg"):
                rarity = symbol_file.stem  # C, R, M, etc.
                symbols[set_code][rarity] = symbol_file

            # Also load PNG files if they exist
            for symbol_file in set_folder.glob("*.png"):
                rarity = symbol_file.stem
                if rarity not in symbols[set_code]:
                    symbols[set_code][rarity] = symbol_file

    print(f"Loaded {len(symbols)} set symbol templates")
    _SET_SYMBOLS = symbols
    return _SET_SYMBOLS


def mouse_callback(event, x, y, flags, param):
    """Handle mouse clicks for ROI selection"""
    global points, image_display
    
    if event == cv2.EVENT_LBUTTONDOWN:
        points.append((x, y))
        
        # Draw the point
        cv2.circle(image_display, (x, y), 5, (0, 255, 0), -1)
        
        # If we have 2 points, draw the rectangle
        if len(points) == 2:
            cv2.rectangle(image_display, points[0], points[1], (0, 255, 0), 2)
        
        cv2.imshow(window_name, image_display)
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

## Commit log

2026-10-01 Serialize Arduino serial transactions
2026-10-02 Add Z jog controls and responsive sensor monitoring
2026-10-02 Launch sorter GUI entry point with calibration controls
2026-10-02 Add hard Z limits and fail-safe homing
    [Main.ino]
2026-10-02 Harden Z homing recovery and start safety
2026-10-03 New Extension with wire cavity
    [new extension.stl]
2026-10-04 Prepare Arduino sketch folder
2026-10-04 Move Arduino firmware into Main sketch folder
2026-10-04 Limit sorter checkout to current version
2026-10-04 Fix Arduino command parsing and Z jog replies
    [Main.ino]
2026-10-04 Restore Friday 7 PM Arduino firmware baseline
2026-10-04 Stabilize Friday firmware serial and Z homing
    [Main.ino]
2026-10-04 Expose Arduino command parsing failures
    [Main.ino]
2026-10-04 Track Z position for pickup calibration
2026-10-04 Fix GUI parameter parsing and set calibrated Z default
    [Main.ino]
2026-10-04 Remove debug serial frame blocking GUI command replies
2026-10-05 Send explicit sort commands to Arduino
2026-10-05 Fix tray coordinate table lookup
    [Main.ino]
2026-10-05 Use calibrated Z value in sorter GUI
2026-10-05 Clamp Z travel and target measured pickup contact
2026-10-05 Align GUI Z calibration with measured steps per mm
2026-10-05 Remove broken post-drop ToF wait loop
    [Main.ino]
2026-10-12 Increase pickup compression to 2mm and Vac1 pulse to 1s
2026-10-13 Recalibrate Z floor for raised bed
2026-10-13 Default to compact UI and move status log under camera
2026-10-13 Add touchscreen Arduino firmware loader and compact COM selector
2026-10-13 Allow deeper manual Z calibration without changing auto pickup limit
2026-10-13 Set calibrated bottom-card Z soft limit to 95000
2026-10-15 Allow Start and Home to wait for homing
2026-10-15 Tighten touchscreen layout for sorter display
2026-10-18 Reject ambiguous MOSS identifications before sorting
    * Add fail-closed product-identification decision guard
    * Test safe identification, ambiguity and set-symbol product consistency
    * Require unambiguous pHash and consistent product IDs before sorting
    * Route uncertain GUI recognitions to reject and require plugin agreement
    * Reset per-scan rejection reason before camera processing
    * Check scanner syntax and identification safety regression tests in CI
2026-10-18 Add safe loading park and return-to-pickup controls
    * Add stopped-only loading park and exact return, with firmware start interlocks
    * Add Load Cards and Return to Pickup controls with Arduino position interlocks
    * Document loading position interlock error E515
    * Expose loading park workflow beside camera and normalize Arduino sensor replies
    * CI-check card loading GUI syntax and Arduino Mega firmware build
    * Document loading workflow, firmware flashing and mechanical safety check
    * Preserve original LF line endings in Current version/Main/Main.ino
    * Preserve original LF line endings in README.md
    * Use Adafruit's actual Arduino Library Manager package name
    * Use Library Manager ID A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
2026-10-19 Fix endstop loading park and reliable Arduino serial handshake
    * Park at real Xmax/Ymin/Zmin endstops; remove unintended sort fallback
    * Use command-aware serial acknowledgements and motion timeouts; support out-of-band STOP
    * Use native Arduino serial and explicit firmware handshake before enabling machine controls
    * Fail closed on old parking firmware and use X/Y/Z endstop-confirmed GUI states
    * Make homing asynchronous and STOP interruptible; bypass unverified Arduino plugins
    * Test verified endstop loading protocol, stale firmware rejection and recovery
    * Make HOME/START interruptible and fail closed if an endstop seek fails
    * Document failed physical endstop park and recovery err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
2026-10-19 Pause stopped auto-sort and stabilize LOAD endstop detection
    * Prevent camera auto-scan and tray commands while sorter is stopped or loading
    * Initialize active-low endstop pullups and reject false no-movement parking
    * Show auto-scan PAUSED when machine stopped instead of misleading ON
    * Block reject-bin commands from stale camera recognition while stopped
    * Regression tests for stopped sorter scan suppression and floating endstop detection
    * Run parked/stopped camera scan safety tests on every MOSS motion PR
    * Require updated endstop pullup firmware version 4 (Current version/Main/Main.ino)
    * Require updated endstop pullup firmware version 4 (Current version/gui_interface_enhanced.p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
2026-10-19 Require explicit home; START arms MOSS without motor movement
    * Make START arm sorting only; require prior HOME/return without moving motors
    * Regressions: START requires prior home and never moves axes
    * CI-verify that START only arms sorting and never homes
    * Clarify HOME is separate; START never invokes homing motion
